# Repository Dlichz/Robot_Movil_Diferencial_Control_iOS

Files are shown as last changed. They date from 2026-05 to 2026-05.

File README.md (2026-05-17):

# 🤖 Robot Móvil Diferencial con Control iOS

> Diseño, construcción y programación de un robot móvil de tracción diferencial controlado de forma inalámbrica desde una app iOS nativa, con evasión autónoma de obstáculos y telemetría en tiempo real.

---

## 🎯 Objetivo General

Diseñar, construir y programar un robot móvil de tracción diferencial controlado de forma inalámbrica desde una aplicación iOS nativa, integrando evasión autónoma de obstáculos, navegación precisa y telemetría en tiempo real.

---

## 📌 Objetivos Específicos

| # | Objetivo | Criterio de Éxito |
|---|---|---|
| 1 | **Hardware y energía** — Implementar un sistema electrónico basado en ESP32 con drivers TB6612FNG, motores N20 con encoder y alimentación LiPo 2S regulada y protegida | Sistema energizado y estable sin sobrecalentamiento |
| 2 | **Control de movimiento** — Lograr giros precisos usando encoders y MPU-6050 con controlador PID | Error promedio < 5° en 10 giros consecutivos de 90° y 180° |
| 3 | **Evasión autónoma** — Detectar obstáculos con VL53L0X y ejecutar maniobra de evasión con prioridad sobre el comando manual | 0 colisiones en 10 pruebas consecutivas con obstáculos a ≤ 20 cm |
| 4 | **Control remoto iOS** — Desarrollar app nativa en Swift con comunicación Bluetooth BLE para comandos en tiempo real | Latencia de respuesta < 100 ms desde la app |
| 5 | **Telemetría en tiempo real** — Visualizar en la app: distancia al obstáculo, velocidad estimada, orientación (yaw) y nivel de batería | Datos actualizados cada ≤ 200 ms |
| 6 | **Chasis 3D** — Diseñar e imprimir un chasis que integre todos los componentes de forma ordenada y desmontable | Todos los componentes fijos, accesibles y sin cables sueltos |

---

## 🛠️ Hardware

### Componentes principales

| Componente | Función |
|---|---|
| ESP32 (Dev Board) | Cerebro del sistema — Bluetooth BLE, lógica de control |
| 2× Motor N20 con encoder | Tracción diferencial con odometría |
| TB6612FNG | Driver de motores de alta eficiencia |
| VL53L0X (ToF) | Detección de obstáculos por láser (±1 mm) |
| MPU-6050 | IMU — acelerómetro + giroscopio para navegación precisa |
| LiPo 2S 7.4V 2200mAh | Fuente de energía principal |
| Módulo Mini-360 | Regulador buck 7.4V → 5V |
| Módulo JESSINIE Tipo C | Carga integrada vía USB-C |
| Ruedas 43mm + ball casters | Sistema de rodadura (tracción diferencial) |
| Chasis impreso en 3D | Estructura diseñada a medida |

### Sistema de energía

```
Batería LiPo 2S (7.4V)
    │
    ├─── Interruptor ON/OFF
    │
    ├─── Fusible PPTC (protección contra cortocircuito)
    │
    ├─── Mini-360 Buck → 5V ──→ ESP32 + Sensores
    │
    └─── TB6612FNG ──────────→ Motores N20
```

---

## 📱 Funcionalidades

- **Control manual** desde app iOS nativa (Swift + CoreBluetooth)
- **Evasión autónoma** de obstáculos en tiempo real (prioridad sobre comando manual)
- **Giros precisos** de 90° y 180° mediante fusión sensorial encoder + IMU
- **Telemetría en vivo** en la app: distancia, velocidad, orientación, batería

---

## 🗂️ Estructura del Repositorio

```
/
├── firmware/          # Código fuente ESP32 (C++ / Arduino framework)
│   ├── src/
│   └── platformio.ini
├── ios-app/           # Aplicación iOS nativa en Swift
├── hardware/          # Esquemáticos y lista de materiales (BOM)
├── cad/               # Archivos del chasis 3D (.f3d / .stl)
├── docs/              # Documento técnico del proyecto por etapas
└── media/             # Fotos y videos de cada etapa
```

---

## 🚀 Etapas del Proyecto

- [x] Definición de objetivos y arquitectura del sistema
- [ ] **Etapa 1** — Control básico de motores (TB6612FNG + N20 + encoders)
- [ ] **Etapa 2** — Comunicación Bluetooth BLE (ESP32 ↔ iPhone)
- [ ] **Etapa 3** — Sensor ToF + lógica de evasión
- [ ] **Etapa 4** — IMU + fusión sensorial + giros precisos (PID)
- [ ] **Etapa 5** — Diseño e impresión del chasis 3D + integración final
- [ ] **Etapa 6** — Pruebas, métricas y documentación final

---

## 🧰 Stack Tecnológico

| Capa | Tecnología |
|---|---|
| Firmware | C++ / Arduino Framework (PlatformIO) |
| Comunicación | Bluetooth BLE (ESP32 ↔ CoreBluetooth) |
| App móvil | Swift (iOS nativo) |
| CAD | Fusion 360 |
| Documentación | Markdown + PDF |

---

## 👤 Autor

**Francisco David Zárate Vásquez: Ingeniero Mecatrónico** — Proyecto de desarrollo técnico personal que combina electrónica, mecánica, control de sistemas y desarrollo de software iOS.

---

## 📄 Licencia

MIT License — libre para usar, modificar y distribuir con atribución.

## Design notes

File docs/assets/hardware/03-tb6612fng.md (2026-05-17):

# Driver de Motores: TB6612FNG

> **Componente:** Driver dual de motores DC con puente H
> **Fabricante:** Toshiba (chip), SparkFun/genéricos (módulo breakout)
> **Función en el robot:** Controlar dirección y velocidad de los dos motores N20

---

## 📑 Tabla de contenidos

- [¿Por qué este componente?](#por-qué-este-componente)
- [¿Qué es y cómo funciona?](#qué-es-y-cómo-funciona)
- [Especificaciones técnicas](#especificaciones-técnicas)
- [Pinout y conexiones](#pinout-y-conexiones)
- [Lógica de control](#lógica-de-control)
- [Sistema de doble alimentación](#sistema-de-doble-alimentación)
- [Comparación con alternativas](#comparación-con-alternativas)
- [Imágenes y referencias](#imágenes-y-referencias)

---

## ¿Por qué este componente?

El ESP32 es un microcontrolador de bajo voltaje (3.3V) y baja corriente (~40 mA por pin). No puede alimentar directamente motores DC, que requieren:

- Voltaje mayor (típicamente 6V–12V)
- Corrientes de 200–500 mA en operación normal, con picos al arrancar
- Capacidad de invertir polaridad para cambiar dirección de giro

Si se conectaran los motores directamente al ESP32:

- Se quemaría el microcontrolador al instante
- Los motores apenas se moverían (poca corriente, bajo voltaje)
- No se podría controlar la dirección de giro

El **TB6612FNG** resuelve esto actuando como intermediario entre el ESP32 y los motores. Recibe señales lógicas de baja potencia y entrega alta corriente a los motores desde una fuente separada (la batería LiPo).

### Razones específicas de elección

1. **Alta eficiencia (~90%)** gracias al uso de MOSFETs en lugar de transistores BJT
2. **Baja caída de voltaje (0.5V)** — los motores reciben casi todo el voltaje de la batería
3. **Bajo calor generado** — no necesita disipador para corrientes pequeñas (motores N20)
4. **Tamaño compacto** — ideal para robots pequeños
5. **Dual integrado** — un solo chip controla los dos motores del robot diferencial

---

## ¿Qué es y cómo funciona?

El TB6612FNG es un driver de motores DC con **dos puentes H** integrados, uno por cada motor.

### El concepto del puente H

Un puente H es un circuito con cuatro interruptores (en este caso, MOSFETs) dispuestos alrededor del motor:

```
         VCC (motor)
              │
         ┌────┴────┐
         │         │
         S1       S3
         │         │
         ├─[Motor]─┤
         │         │
         S2       S4
         │         │
         └────┬────┘
              │
             GND
```

Al cerrar diferentes combinaciones de interruptores, se controla el flujo de corriente a través del motor:

| Acción | Interruptores cerrados | Efecto |
|---|---|---|
| Adelante | S1 + S4 | Corriente fluye izquierda → derecha |
| Atrás | S2 + S3 | Corriente fluye derecha → izquierda |
| Freno activo | S1 + S3 (o S2 + S4) | Cortocircuito controlado del motor |
| Coast (libre) | Ninguno | Motor gira por inercia |

El TB6612FNG implementa esta lógica internamente con MOSFETs, controlados desde fuera mediante señales lógicas simples (HIGH/LOW).

### Control de velocidad con PWM

Además de la dirección, el TB6612FNG permite controlar la velocidad mediante **PWM** (Pulse Width Modulation). En lugar de aplicar 7.4V constantes, aplica pulsos rápidos cuyo "ancho" determina la potencia promedio:

- PWM al 100% → motor a velocidad máxima
- PWM al 50% → motor a media velocidad
- PWM al 0% → motor detenido

El ESP32 genera la señal PWM por hardware usando su periférico **LEDC**, sin gastar ciclos de CPU.

---

## Especificaciones técnicas

| Parámetro | Valor |
|---|---|
| Voltaje de motores (VM) | 2.5V – 13.5V |
| Voltaje de lógica (VCC) | 2.7V – 5.5V |
| Corriente continua por canal | 1.2 A |
| Corriente pico por canal | 3.2 A |
| Frecuencia PWM máxima | 100 kHz |
| Canales de motor | 2 (Motor A y Motor B) |
| Tecnología interna | MOSFET (mayor eficiencia que BJT) |
| Protecciones incluidas | Térmica, bajo voltaje, sobre-corriente |

---

## Pinout y conexiones

El módulo TB6612FNG tiene tres grupos de pines:

### Grupo 1: Alimentación

| Pin | Función | Conexión en el robot |
|---|---|---|
| **VM** | Voltaje para motores | Batería LiPo 2S (+7.4V) directo |
| **VCC** | Voltaje para lógica del chip | 5V regulado desde Mini-360 |
| **GND** | Tierra | GND común con ESP32 y batería |

> ⚠️ VM y VCC son independientes. Esto permite alimentar motores con alto voltaje mientras la lógica del chip opera con voltaje bajo y estable.

### Grupo 2: Señales de control desde el ESP32

| Pin TB6612FNG | Pin ESP32 | Función |
|---|---|---|
| STBY | GPIO 13 | Standby — HIGH activa el chip, LOW lo apaga |
| PWMA | GPIO 25 | PWM Motor A — controla velocidad (0–255) |
| AIN1 | GPIO 26 | Dirección Motor A (bit 1) |
| AIN2 | GPIO 27 | Dirección Motor A (bit 2) |
| PWMB | GPIO 33 | PWM Motor B — controla velocidad (0–255) |
| BIN1 | GPIO 14 | Dirección Motor B (bit 1) |
| BIN2 | GPIO 12 | Dirección Motor B (bit 2) |

### Grupo 3: Salidas a motores

| Pin TB6612FNG | Conexión |
|---|---|
| AO1 | Motor A — cable (+) |
| AO2 | Motor A — cable (−) |
| BO1 | Motor B — cable (+) |
| BO2 | Motor B — cable (−) |

> 💡 La polaridad del motor (qué cable va a AO1 y cuál a AO2) determina qué dirección se considera "adelante". Si el motor gira al revés, basta con invertir AO1↔AO2 o cambiar la lógica en el código.

---

## Lógica de control

Para cada motor, la combinación de IN1, IN2 y PWM determina su comportamiento:

| IN1 | IN2 | PWM | Estado del motor |
|---|---|---|---|
| HIGH | LOW | 0–255 | Adelante (velocidad según PWM) |
| LOW | HIGH | 0–255 | Atrás (velocidad según PWM) |
| HIGH | HIGH | cualquiera | Freno activo (short brake) |
| LOW | LOW | cualquiera | Coast (motor libre, gira por inercia) |
| cualquiera | cualquiera | 0 | Detenido |

### Ejemplo de código

```cpp
// Motor A hacia adelante a velocidad media
digitalWrite(AIN1, HIGH);
digitalWrite(AIN2, LOW);
ledcWrite(canalPWMA, 128);   // 128/255 ≈ 50%

// Motor A hacia atrás a velocidad máxima
digitalWrite(AIN1, LOW);
digitalWrite(AIN2, HIGH);
ledcWrite(canalPWMA, 255);

// Frenar Motor A
digitalWrite(AIN1, HIGH);
digitalWrite(AIN2, HIGH);
```

### Sobre el pin STBY

El pin **STBY (Standby)** actúa como interruptor maestro del chip:

- **STBY = HIGH** → Chip activo, los motores responden a las señales
- **STBY = LOW** → Chip en bajo consumo, los motores no se mueven sin importar las señales

En el firmware, STBY se pone en HIGH una vez al iniciar (`setup()`). Olvidarlo es un error común que causa que el robot no se mueva aunque el código parezca correcto.

---

## Sistema de doble alimentación

```
                    Batería LiPo 2S (7.4V)
                           │
                           ├──→ VM (motores reciben 7.4V)
                           │
                    Mini-360 (regulador DC-DC)
                           │
                           ├──→ 5V → ESP32 VIN
                           │
                           ├──→ 5V → TB6612FNG VCC (lógica)
                           │
                           └──→ GND común a todo el sistema
```

### ¿Por qué dos fuentes separadas?

1. Los **motores** consumen corrientes grandes y generan picos al arrancar
2. La **lógica** del ESP32 y del chip TB6612FNG necesita voltaje estable
3. Si todo compartiera el mismo riel, los picos de corriente del motor causarían caídas de voltaje que podrían reiniciar el ESP32 o introducir errores

Esta separación es **estándar en cualquier robot móvil bien diseñado** y aumenta significativamente la fiabilidad del sistema.

---

## Comparación con alternativas

| Característica | TB6612FNG | L298N | DRV8833 |
|---|---|---|---|
| Tecnología interna | MOSFET | BJT (Darlington) | MOSFET |
| Eficiencia | ~90% | ~60% | ~90% |
| Caída de voltaje | 0.5V | 2.0V+ | 0.5V |
| Corriente continua | 1.2 A | 2.0 A | 1.5 A |
| Calor generado | Bajo | Alto (necesita disipador) | Bajo |
| Tamaño del módulo | Pequeño | Grande | Muy pequeño |
| Costo aproximado | $3 USD | $2 USD | $3 USD |
| Recomendado para | Robots pequeños/medianos | Motores grandes | Robots muy compactos |

### ¿Por qué TB6612FNG y no L298N?

El L298N es más común en kits para principiantes, pero tiene desventajas serias para este proyecto:

- Pierde 2V o más como calor → la batería se descarga más rápido
- Requiere disipador térmico → más volumen
- Menor eficiencia → menor autonomía del robot

El TB6612FNG aprovecha mejor cada miliamperio de la batería LiPo, lo cual es crítico en un robot pequeño con batería limitada.

---

## Imágenes y referencias

### Fotos del componente

<!-- TODO: Agregar fotos -->
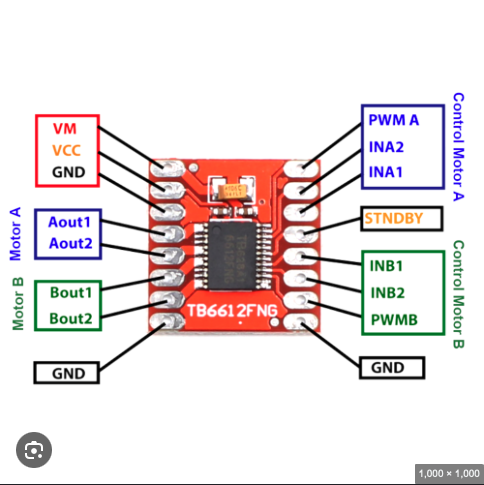
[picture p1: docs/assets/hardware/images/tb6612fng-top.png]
Módulo TB6612FNG vista superior

### Diagrama de conexiones en el robot

<!-- TODO: Exportar diagrama de Fritzing aquí -->
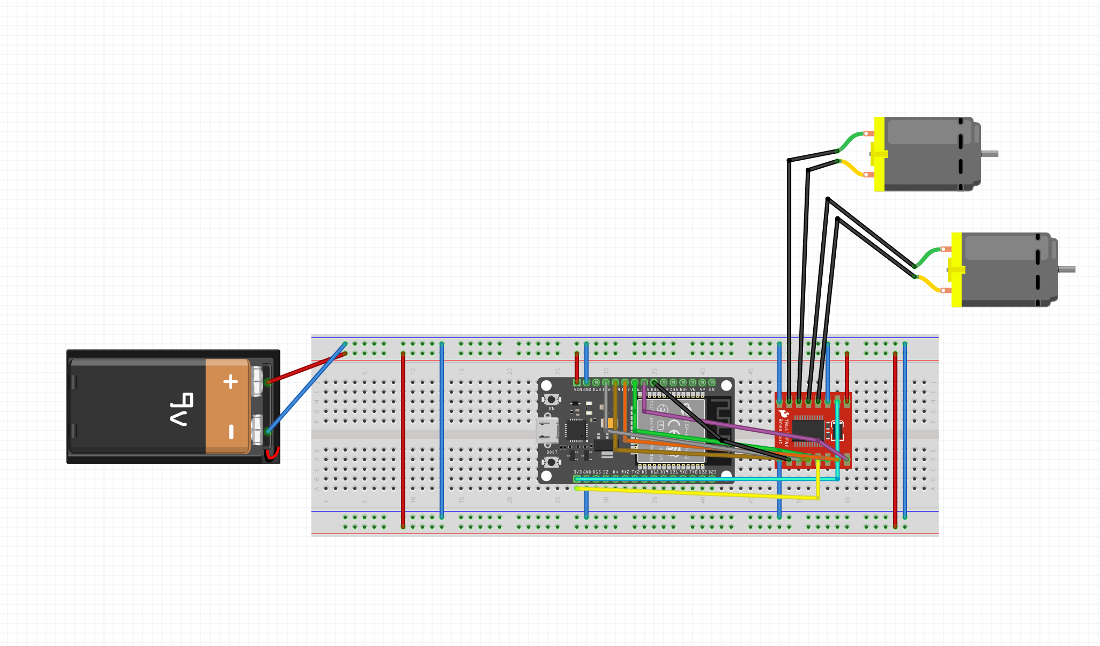
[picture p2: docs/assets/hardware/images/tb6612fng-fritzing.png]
Conexión TB6612FNG + ESP32 + motores

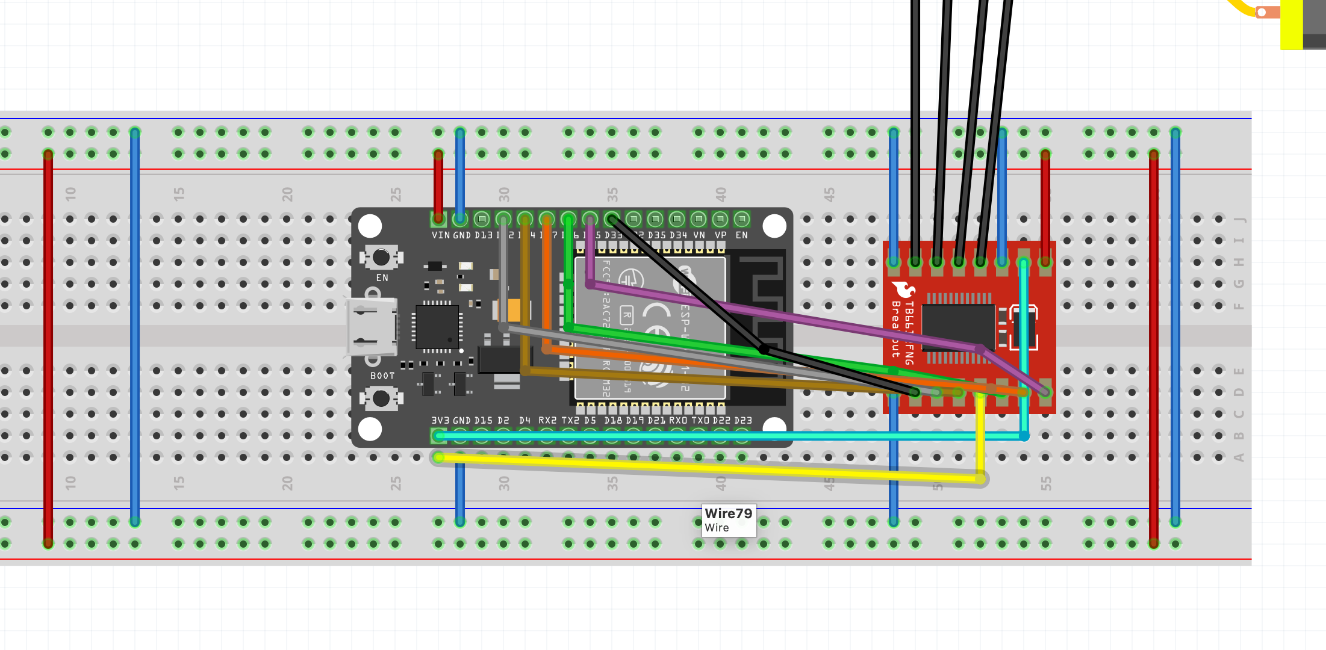
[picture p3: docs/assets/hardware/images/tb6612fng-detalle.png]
Detalle de conexión


### Documentos de referencia

- [Datasheet oficial Toshiba TB6612FNG](https://www.sparkfun.com/datasheets/Robotics/TB6612FNG.pdf)
- [Hookup Guide de SparkFun](https://learn.sparkfun.com/tutorials/tb6612fng-hookup-guide)
- [Librería oficial SparkFun TB6612FNG (Arduino)](https://github.com/sparkfun/SparkFun_TB6612FNG_Arduino_Library)

---

## Notas de implementación

### Estado actual en el proyecto

- [x] Componente seleccionado y justificado
- [x] Pinout definido para integración con ESP32
- [x] Código base de control implementado (`src/main.cpp`)
- [x] Lógica validada en simulación (Wokwi)
- [x] Diagrama de cableado en Fritzing
- [ ] Pruebas con hardware real
- [ ] Ajuste fino de PWM según comportamiento de los motores N20

### Próximos pasos

1. Simular conexión en proteus o similar
2. Conectar físicamente sobre protoboard y validar lógica
3. Integrar con encoders para control de velocidad en lazo cerrado
4. Caracterizar respuesta motor → PWM real

---

*Documento mantenido por: Francisco David Zárate Vásquez*
*Última actualización: 16 de mayo 2026*

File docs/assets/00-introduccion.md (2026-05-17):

# 00. Introducción

## 1. Descripción del Proyecto

Este proyecto consiste en el diseño, construcción y programación de un robot móvil de tracción diferencial controlado de forma inalámbrica desde una aplicación iOS nativa. El sistema integra evasión autónoma de obstáculos, navegación precisa mediante fusión sensorial y telemetría en tiempo real visualizada desde un iPhone.

El proyecto combina disciplinas de electrónica, mecánica, control de sistemas y desarrollo de software móvil, representando una aplicación práctica completa de la ingeniería mecatrónica.

---

## 2. Motivación

La ingeniería mecatrónica integra mecánica, electrónica, control y programación. Sin embargo, pocas veces se tienen la oportunidad de aplicar todas estas áreas en un solo proyecto personal, fuera del entorno académico o laboral formal.

Este proyecto nace de la intención de poner a prueba esos conocimientos de forma autónoma, añadiendo además el desarrollo de una aplicación iOS nativa como diferenciador técnico. La combinación de un sistema embebido en ESP32 con una app desarrollada en Swift representa un stack tecnológico completo de extremo a extremo, desde el firmware hasta la interfaz de usuario.

---

## 3. Objetivo General

Diseñar, construir y programar un robot móvil de tracción diferencial controlado de forma inalámbrica desde una aplicación iOS nativa, integrando evasión autónoma de obstáculos, navegación precisa y telemetría en tiempo real.

---

## 4. Objetivos Específicos

### 4.1 Hardware y Sistema de Energía
Implementar un sistema electrónico funcional basado en ESP32, con driver TB6612FNG, motores N20 con encoder y alimentación LiPo 2S regulada y protegida mediante fusible PPTC y módulo buck Mini-360.

**Criterio de éxito:** Sistema energizado y estable sin sobrecalentamiento durante operación continua.

### 4.2 Control de Movimiento Preciso
Lograr giros de 90° y 180° con error promedio menor a 5°, mediante un controlador PID que fusiona la información de los encoders de los motores N20 y el giroscopio del MPU-6050.

**Criterio de éxito:** Error promedio < 5° en 10 giros consecutivos de cada ángulo.

### 4.3 Evasión Autónoma de Obstáculos
Implementar un comportamiento reactivo que detecte obstáculos mediante el sensor ToF VL53L0X a una distancia menor o igual a 20 cm, ejecutando una maniobra de evasión en menos de 500 ms con prioridad sobre cualquier comando manual.

**Criterio de éxito:** Cero colisiones en 10 pruebas consecutivas con obstáculos a ≤ 20 cm.

### 4.4 Control Remoto desde iPhone
Desarrollar una aplicación iOS nativa en Swift que se comunique con el ESP32 mediante Bluetooth BLE (CoreBluetooth) para enviar comandos de movimiento en tiempo real.

**Criterio de éxito:** Latencia de respuesta menor a 100 ms desde la interacción en la app hasta la respuesta del robot.

### 4.5 Telemetría en Tiempo Real
Visualizar en la app iOS datos del robot actualizados en vivo: distancia al obstáculo más cercano, velocidad estimada, orientación (yaw) y nivel de batería.

**Criterio de éxito:** Datos actualizados cada ≤ 200 ms sin pérdida de conexión en operación normal.

### 4.6 Chasis Diseñado a Medida
Diseñar e imprimir en 3D un chasis que integre todos los componentes de forma ordenada, accesible para mantenimiento y sin cables sueltos.

**Criterio de éxito:** Todos los componentes fijos y desmontables sin necesidad de herramientas especiales.

---

## 5. Alcances

- El robot opera en superficies planas de interiores (escritorio, mesa).
- El control remoto funciona dentro del rango Bluetooth BLE (aproximadamente 10 metros en interiores).
- La evasión de obstáculos es reactiva, no predictiva — el robot responde al obstáculo cuando lo detecta, no planifica rutas.
- La app iOS es compatible con iPhone (iOS 16 en adelante).
- El sistema de carga es integrado mediante puerto USB-C.

---

## 6. Limitaciones

- No se implementa navegación autónoma completa ni mapeo del entorno (SLAM).
- El robot no está diseñado para superficies irregulares, rampas o exteriores.
- La app no incluye modo multijugador ni control desde múltiples dispositivos simultáneamente.
- La precisión de la odometría puede degradarse en superficies con poca fricción.

---

## 7. Estructura del Documento

| Capítulo | Contenido |
|---|---|
| 00. Introducción | Este documento — contexto, objetivos, alcances |
| 01. Marco Teórico | Fundamentos técnicos de cada subsistema |
| 02. Diseño de Hardware | Componentes, esquemáticos, sistema de energía, chasis |
| 03. Diseño de Firmware | Arquitectura de software del ESP32, PID, BLE |
| 04. Aplicación iOS | Arquitectura de la app, CoreBluetooth, telemetría |
| 05. Pruebas y Resultados | Métricas reales, tablas, gráficas comparativas |
| 06. Conclusiones | Logros, problemas resueltos, trabajo futuro |

---

*Última actualización: Mayo 2026*

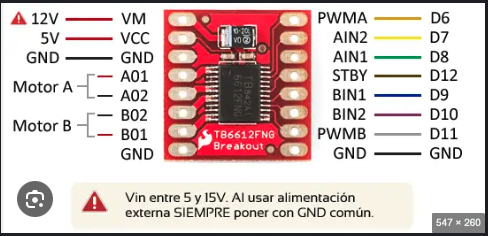
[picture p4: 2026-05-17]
docs/assets/hardware/images/tb6612fng-pinout.png

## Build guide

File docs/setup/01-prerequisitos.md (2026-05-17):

# 01 — Prerrequisitos

> Antes de instalar las herramientas, necesitas tener listo el sistema, las cuentas y el hardware básico.

---

## 💻 Sistema operativo

### macOS (recomendado, este proyecto se desarrolló aquí)

- **Versión mínima:** macOS 12 (Monterey) o superior
- **Versión usada en el proyecto:** macOS Sonoma / Sequoia
- **Chip:** Intel o Apple Silicon (M1/M2/M3/M4) — ambos funcionan

### Linux

- Ubuntu 20.04+, Fedora 36+, o equivalente
- Todas las herramientas funcionan, pero algunos comandos de las guías cambian

### Windows

- Windows 10 o 11
- Algunas herramientas (como Fritzing) tienen mejor experiencia en Mac/Linux

---

## 🛠️ Hardware necesario

### Mínimo para empezar

- Computadora con al menos 8 GB de RAM
- 10 GB de espacio libre en disco
- Conexión a internet estable

### Para programar el robot

- **ESP32 DevKit V1** (30 pines, basado en ESP32-WROOM-32)
- **Cable USB con datos** (NO solo de carga)
  - Recomendado: USB-A a Micro-USB, o USB-C a Micro-USB

### Para el robot completo (no necesario para programar)

- Driver de motores TB6612FNG
- 2× Micro motorreductor N20 con encoder
- Sensor ToF VL53L0X
- Giroscopio MPU-6050
- Batería LiPo 2S 7.4V 2200 mAh
- Módulo de carga USB-C para LiPo 2S
- 2× Módulos Mini-360 (reguladores DC-DC)
- Interruptor SPST + fusible PPTC
- Protoboard + cables jumper
- Multímetro (opcional, muy recomendado)

---

## 👤 Cuentas necesarias

### Obligatorias

| Servicio | Para qué |
|---|---|
| [GitHub](https://github.com) | Versionado del código, descargar el repositorio |
| [Wokwi](https://wokwi.com) | Simulador online (login con GitHub o Google) |

### Opcionales (recomendadas)

| Servicio | Para qué |
|---|---|
| [Fritzing](https://fritzing.org) | Si quieres compartir tus diagramas |
| [Foro de Fritzing](https://forum.fritzing.org) | Descargar componentes custom |
| [PlatformIO](https://platformio.org) | No estrictamente necesaria pero útil |

---

## 🔧 Conocimientos previos útiles (no obligatorios)

Este proyecto está documentado para que cualquiera pueda seguirlo, pero te será más fácil si tienes nociones básicas de:

- **Programación en C/C++** o cualquier lenguaje
- **Electrónica básica** (qué es voltaje, corriente, resistencia)
- **Línea de comandos** (terminal de Mac/Linux)
- **Git** (clonar repositorios, commits)

Si no tienes ninguno de estos, no te preocupes — las guías incluyen explicaciones de los conceptos clave.

---

## ✅ Checklist antes de continuar

Antes de pasar a la siguiente guía, asegúrate de tener:

- [ ] Tu Mac/PC con el sistema operativo actualizado
- [ ] Al menos 10 GB de espacio libre en disco
- [ ] Cuenta de GitHub creada
- [ ] Conexión a internet estable
- [ ] (Opcional) ESP32 + cable USB para pruebas con hardware real

---

## 🆘 Problemas comunes

### "Mi Mac es antiguo, ¿funcionará?"

Si tu Mac soporta macOS 12 o superior, sí. Cualquier MacBook desde 2017 en adelante debería andar sin problemas.

### "Tengo Windows, ¿puedo seguir el proyecto?"

Sí, pero las guías están escritas con comandos de Mac. Necesitarás traducir algunos a PowerShell o cmd. La lógica es idéntica.

### "No tengo el ESP32 todavía"

No hay problema. Puedes:
1. Hacer todo el setup
2. Escribir y compilar el código
3. Simular en Wokwi (no requiere hardware)

El hardware solo es necesario para la fase final de pruebas.

---

[← Volver al índice](README.md) | [Siguiente: VS Code →](02-vscode.md)

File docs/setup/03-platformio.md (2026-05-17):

# 03 — PlatformIO

> **PlatformIO** es el sistema de build profesional para microcontroladores. Es lo que toma tu código C++ y lo convierte en un binario que el ESP32 puede ejecutar.

---

## 🎯 ¿Qué es PlatformIO?

PlatformIO es un ecosistema de desarrollo de software libre y de código abierto para sistemas embebidos y aplicaciones de Internet de las Cosas. Maneja:

- **Compilación** del código C++ a binario para ESP32 (u otros chips)
- **Descarga de librerías** automáticamente
- **Gestión de toolchains** (compiladores específicos)
- **Subida del firmware** a la placa
- **Monitoreo del puerto serial**
- **Tests unitarios**

---

## 🆚 ¿Por qué no Arduino IDE?

| Característica | Arduino IDE | PlatformIO |
|---|---|---|
| Compilación | Sí | Sí (más rápido) |
| Gestión de librerías | Manual | Automática (declaras en `platformio.ini`) |
| Estructura del proyecto | Plana, 1 archivo `.ino` | Profesional, separa `src/`, `lib/`, `include/`, `test/` |
| IDE | Propio (limitado) | Funciona en VS Code (mucho mejor) |
| Soporta múltiples chips | Sí, con plugins | Sí, nativo (1000+ placas) |
| Reproducibilidad | Dependiente del entorno | Configuración versionable en `platformio.ini` |
| Industria | Hobby | Profesional |

PlatformIO es **profesional**.

---

## 📥 Instalación

PlatformIO se instala como **extensión de VS Code**, no como aplicación independiente.

### Pasos

1. Abre VS Code
2. Ve al panel de extensiones (`Cmd + Shift + X`)
3. Busca **"PlatformIO IDE"**
4. Click en **"Install"**
5. ⏳ Espera 3-5 minutos
   - PlatformIO descarga:
     - Python embebido (~100 MB)
     - Toolchain de Xtensa para ESP32 (~150 MB)
     - Framework de Arduino para ESP32 (~50 MB)
6. Cuando termine, VS Code pedirá reiniciar — acepta
7. Al reabrir, verás la **carita de alien** 👽 en la barra lateral izquierda

### Verificación

Click en el ícono 👽 → debería aparecer un panel con "PROJECT TASKS", "QUICK ACCESS", "Debug", "Miscellaneous".

---

## 🎓 Conceptos clave

### El archivo `platformio.ini`

Es el **corazón** del proyecto. Define qué chip, qué framework y qué librerías usar.

Ejemplo del archivo de este proyecto:

```ini
[env:esp32dev]
platform = espressif32
board = esp32dev
framework = arduino
monitor_speed = 115200
```

Línea por línea:

| Línea | Significado |
|---|---|
| `[env:esp32dev]` | Nombre del entorno. Puedes tener varios (por ej. `[env:esp32]`, `[env:esp32-debug]`) |
| `platform = espressif32` | Familia de chips (Espressif = ESP32, ESP8266) |
| `board = esp32dev` | Modelo específico de placa (ESP32 DevKit V1) |
| `framework = arduino` | Framework de programación (alternativa: ESP-IDF) |
| `monitor_speed = 115200` | Velocidad del puerto serial en baudios |

### Estructura de un proyecto PlatformIO

```
mi-proyecto/
├── platformio.ini          # Configuración del proyecto
├── src/
│   └── main.cpp            # Código principal
├── include/                # Headers personalizados (.h)
├── lib/                    # Librerías propias del proyecto
├── test/                   # Tests unitarios
└── .pio/                   # Carpeta generada (NO editar, NO subir a Git)
    └── build/
        └── esp32dev/
            ├── firmware.bin    # Binario compilado
            └── firmware.elf    # Versión con info de debug
```

### Diferencias con Arduino IDE

| Arduino IDE | PlatformIO |
|---|---|
| Un solo archivo `.ino` | Múltiples `.cpp` y `.h` en `src/` |
| `#include <Arduino.h>` automático | Debes incluirlo manualmente |
| Funciones se pueden usar antes de declararlas | Necesitas declaraciones adelantadas |
| Librerías globales | Librerías por proyecto |

---

## 🛠️ Comandos esenciales

PlatformIO funciona tanto por **interfaz gráfica** (botones en VS Code) como por **terminal** (`pio`).

### Por terminal

| Comando | Descripción |
|---|---|
| `pio run` | Compilar |
| `pio run --target upload` | Compilar + subir al ESP32 |
| `pio run --target clean` | Limpiar archivos compilados |
| `pio device monitor` | Abrir monitor serial |
| `pio device list` | Listar puertos seriales detectados |
| `pio update` | Actualizar plataformas y librerías |
| `pio platform list` | Ver plataformas instaladas |

### Por interfaz gráfica

En la barra inferior azul de VS Code aparecen estos íconos (de izquierda a derecha):

| Ícono | Función | Equivalente terminal |
|---|---|---|
| 🏠 | PIO Home | — |
| ✓ | Build | `pio run` |
| → | Upload | `pio run --target upload` |
| 🗑️ | Clean | `pio run --target clean` |
| 📁 | Tasks | — |
| ⚡ | Serial Monitor | `pio device monitor` |

---

## 🚀 Crear un proyecto nuevo (referencia)

Si quieres empezar otro proyecto en el futuro:

1. Click en el ícono 👽 de PlatformIO
2. Click en **"PIO Home"** → **"+ New Project"**
3. Llena:
   - **Name:** nombre del proyecto
   - **Board:** busca tu placa (ej. `ESP32 Dev Module`)
   - **Framework:** `Arduino`
   - **Location:** carpeta donde guardarlo
4. Click **"Finish"**
5. Espera a que se inicialice

Para este proyecto, **no necesitas crear uno nuevo** — ya está creado en `firmware/esp32/`.

---

## 🔧 Cómo agregar una librería

Cuando llegues a sensores, vas a necesitar librerías como Adafruit_MPU6050 o Adafruit_VL53L0X.

### Método 1: Editar `platformio.ini` (recomendado, versionable)

Agrega bajo el entorno:

```ini
[env:esp32dev]
platform = espressif32
board = esp32dev
framework = arduino
monitor_speed = 115200
lib_deps =
    adafruit/Adafruit MPU6050 @ ^2.2.4
    adafruit/Adafruit VL53L0X @ ^1.2.4
```

La próxima vez que compiles, PlatformIO las descarga automáticamente.

### Método 2: Por interfaz

1. Click en el ícono 👽
2. **PIO Home → Libraries**
3. Busca la librería
4. Click en **"Add to Project"**

---

## 🆘 Problemas comunes

### "command not found: pio"

Pasa cuando usas una terminal externa (no la integrada de VS Code).

**Solución 1:** Usa la terminal interna de VS Code (`Ctrl + ñ`). Esa SÍ tiene `pio` en el PATH.

**Solución 2 (permanente):** Agrega esta línea a tu `~/.zshrc`:

```bash
export PATH="$PATH:$HOME/.platformio/penv/bin"
```

Luego ejecuta `source ~/.zshrc` para aplicar el cambio.

### "Failed to connect to ESP32: Wrong boot mode detected"

El ESP32 está en estado raro.

**Solución:** Mantén presionado el botón **BOOT** (o **IO0**) en la placa mientras inicias el upload. Suéltalo cuando empiece a escribir.

### "Permission denied: /dev/cu.usbserial-XXXX"

En Mac, a veces el puerto serial no tiene permisos.

**Solución:**
```bash
sudo chmod 666 /dev/cu.usbserial-0001
```

### "Compilación tarda muchísimo la primera vez"

**Es normal.** La primera vez PlatformIO descarga el toolchain (~200 MB). Las siguientes compilaciones son rápidas (5-15 segundos).

### "Errores que `Serial` no existe, `pinMode` no existe..."

Falta `#include <Arduino.h>` al inicio de `main.cpp`. En PlatformIO no es automático como en Arduino IDE.

---

## ✅ Checklist al terminar

- [ ] PlatformIO instalado como extensión
- [ ] Veo el ícono 👽 en VS Code
- [ ] Puedo abrir el proyecto `firmware/esp32/` y ver `platformio.ini`
- [ ] Sé compilar con el botón ✓ o con `pio run`
- [ ] Sé que el binario sale en `.pio/build/esp32dev/firmware.bin`

---

[← Anterior: VS Code](02-vscode.md) | [Siguiente: Wokwi →](04-wokwi.md)

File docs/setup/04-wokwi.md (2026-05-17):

# 04 — Wokwi

> **Wokwi** es un simulador online de microcontroladores. Permite probar tu código sin tener el hardware físico, ideal para validar lógica antes de invertir en componentes.

---

## 🎯 ¿Qué hace Wokwi?

- Simula el ESP32 (y muchos otros chips) ejecutando tu código real
- Provee componentes virtuales (LEDs, sensores, pantallas)
- Tiene **analizador lógico** y monitor serial integrados
- Soporta WiFi y Bluetooth simulados (limitado)

---

## 🆚 Dos formas de usar Wokwi

### Opción A: Wokwi en el navegador (recomendada para empezar)

- **URL:** https://wokwi.com
- **Ventajas:** Sin instalaciones, compila en sus servidores, siempre funciona
- **Desventajas:** Requiere internet, no integra con tu proyecto PlatformIO

### Opción B: Extensión Wokwi para VS Code

- Se instala como extensión
- Usa el `firmware.bin` compilado por PlatformIO
- **Ventajas:** Integrado con tu flujo de desarrollo
- **Desventajas:** Tiene bugs ocasionales en Mac (especialmente el monitor serial)

⚠️ **Recomendación del proyecto:** Para esta etapa, usa **Wokwi en el navegador**. Es más estable y rápido.

---

## 🌐 Opción A: Wokwi en el navegador

### Setup inicial

1. Ve a **https://wokwi.com**
2. Click en **"Log in"** (arriba a la derecha)
3. Inicia sesión con GitHub o Google
4. Listo, no requiere instalación

### Cómo abrir el proyecto

#### Método 1: Crear desde cero

1. Click en **"New Project"** → **"ESP32"**
2. Se abre un editor con 2 archivos:
   - `sketch.ino` — código (formato Arduino)
   - `diagram.json` — esquemático

#### Método 2: Cargar el proyecto existente

1. Abre **https://wokwi.com**
2. Click en **"New Project"** → **"ESP32"**
3. En la pestaña **`sketch.ino`**, borra el contenido y pega el código de `firmware/esp32/src/main.cpp`
   - ⚠️ **Importante:** quita la línea `#include <Arduino.h>` (Wokwi web no la necesita)
4. En la pestaña **`diagram.json`**, borra y pega el contenido de `firmware/esp32/diagram.json`
5. Click en el botón **▶ verde** para arrancar la simulación

### Interfaz de Wokwi web

```
┌──────────────────────────────────────────────────────┐
│  💾 SAVE  📤 SHARE   nombre-proyecto                  │
├──────────────────────────────────────────────────────┤
│                                                       │
│  [sketch.ino] [diagram.json] [Library Manager]        │
│                                                       │
│  Aquí escribes/pegas el código                        │
│                                                       │
│                                                       │
├────────────────────────┬─────────────────────────────┤
│                        │ [Simulation]                 │
│                        │  ▶ ⏸ 🔄  (controles)        │
│                        │                              │
│                        │  Aquí aparece el circuito    │
│                        │                              │
│  Monitor Serial:       │                              │
│  > _                   │                              │
└────────────────────────┴─────────────────────────────┘
```

### Cómo usar el monitor serial

1. Después de darle ▶ Play, busca el **monitor serial** en la parte inferior izquierda
2. Si no aparece, presiona **`Ctrl + Shift + S`** para mostrarlo
3. Click dentro del monitor → escribe comandos (ej. `w`)
4. Presiona Enter

---

## 💻 Opción B: Wokwi como extensión de VS Code

### Instalación

1. En VS Code, ve al panel de extensiones (`Cmd + Shift + X`)
2. Busca **"Wokwi Simulator"**
3. Click en **"Install"**
4. Reinicia VS Code

### Activar licencia gratuita

Wokwi requiere licencia incluso en su versión gratis (para uso personal).

1. `Cmd + Shift + P` → escribe **"Wokwi: Request a new License"**
2. Se abre el navegador
3. Inicia sesión con GitHub o Google
4. Acepta los términos
5. Vuelve a VS Code — la licencia se activa sola

### Archivos necesarios en el proyecto

Para usar Wokwi en VS Code, tu proyecto debe tener:

```
firmware/esp32/
├── platformio.ini
├── diagram.json       # Esquemático
├── wokwi.toml         # Configuración de Wokwi
└── src/
    └── main.cpp
```

#### `diagram.json`

Define los componentes del circuito virtual. Ejemplo mínimo:

```json
{
  "version": 1,
  "author": "Tu Nombre",
  "editor": "wokwi",
  "parts": [
    {
      "type": "board-esp32-devkit-c-v4",
      "id": "esp",
      "top": 0,
      "left": 0,
      "attrs": {}
    }
  ],
  "connections": []
}
```

#### `wokwi.toml`

Le dice a Wokwi dónde está el binario compilado:

```toml
[wokwi]
version = 1
firmware = '.pio/build/esp32dev/firmware.bin'
elf = '.pio/build/esp32dev/firmware.elf'
```

⚠️ **Importante:** la ruta `esp32dev` debe coincidir con el nombre del entorno en `platformio.ini`. Si tu entorno se llama `esp32`, cambia a `.pio/build/esp32/`.

### Cómo correr la simulación

1. Compila el código primero: botón ✓ o `pio run`
2. Abre el archivo `diagram.json` en VS Code
3. `Cmd + Shift + P` → **"Wokwi: Start Simulator"**
4. Se abre el simulador en una pestaña de VS Code
5. Click en el botón **▶ verde** para arrancar

### El bug del monitor serial vacío

Si el monitor de Wokwi no muestra el output del ESP32:

**Solución 1:** Click DENTRO del monitor para enfocarlo, luego presiona Reset 🔄

**Solución 2:** Detén, cierra y reabre el simulador

**Solución 3:** Si nada funciona, usa wokwi.com en el navegador

---

## 🧩 Componentes que SÍ existen en Wokwi

Estos son los más útiles para este proyecto:

| Componente | ID en Wokwi |
|---|---|
| ESP32 DevKit | `board-esp32-devkit-c-v4` |
| LED | `wokwi-led` |
| Resistencia | `wokwi-resistor` |
| Pulsador | `wokwi-pushbutton` |
| Sensor ultrasónico (sustituto del ToF) | `wokwi-hc-sr04` |
| MPU6050 | `wokwi-mpu6050` |
| Pantalla OLED | `wokwi-ssd1306` |
| Analizador lógico | `wokwi-logic-analyzer` |
| Slide switch | `wokwi-slide-switch` |

### Componentes que NO existen (cuidado)

- ❌ `wokwi-l298n` o `wokwi-tb6612fng` (no hay drivers de motores nativos)
- ❌ `wokwi-dc-motor` (no hay motores DC simulables)
- ❌ `wokwi-vl53l0x` (no hay sensor ToF, usar HC-SR04 como sustituto)

Para drivers de motores en Wokwi, se simulan con LEDs que representan las señales de control.

---

## 📚 Recursos útiles

- [Documentación oficial de Wokwi](https://docs.wokwi.com/)
- [Lista de componentes disponibles](https://docs.wokwi.com/parts/)
- [Ejemplos de proyectos](https://wokwi.com/projects)

---

## 🆘 Problemas comunes

### "Wokwi no encuentra el firmware.bin"

- Verifica que compilaste primero (`pio run` o botón ✓)
- Verifica que la ruta en `wokwi.toml` coincide con tu carpeta de build
- Si tu env es `esp32dev` → ruta `.pio/build/esp32dev/firmware.bin`
- Si tu env es `esp32` → ruta `.pio/build/esp32/firmware.bin`

### "Los componentes no aparecen en el simulador"

Verifica que los `type` en `diagram.json` sean válidos (lista arriba). Wokwi ignora silenciosamente componentes inexistentes.

### "La simulación está pausada al abrirse"

Click en el botón **▶ verde** para arrancar. No corre automáticamente.

### "El monitor serial está vacío en VS Code"

Bug conocido en Mac. Soluciones (en orden):
1. Click dentro del monitor + Reset 🔄
2. Cerrar y reabrir simulador
3. Cambiar a wokwi.com en el navegador

### "Wokwi web no compila mi código"

Verifica:
- No tienes `#include <Arduino.h>` (Wokwi web no lo necesita, sí da error)
- No tienes errores de sintaxis (revisa el panel de errores debajo del editor)

---

## ✅ Checklist al terminar

- [ ] Tengo cuenta en Wokwi (vía GitHub o Google)
- [ ] Puedo abrir https://wokwi.com sin problemas
- [ ] (Opcional) Extensión Wokwi instalada y activada en VS Code
- [ ] Sé la diferencia entre wokwi.com y la extensión

---

[← Anterior: PlatformIO](03-platformio.md) | [Siguiente: Fritzing →](05-fritzing.md)

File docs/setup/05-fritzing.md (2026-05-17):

# 05 — Fritzing

> **Fritzing** es la herramienta para diseñar y documentar circuitos electrónicos. Lo usamos para crear los diagramas de conexión del robot.

---

## 🎯 ¿Qué es Fritzing?

Es un programa que permite:

- Diseñar circuitos en **vista de protoboard** (cómo se ven los cables reales)
- Generar **esquemáticos** (representación eléctrica formal)
- Diseñar **PCBs** (placas de circuito impreso)
- Exportar imágenes para documentación

Es muy usado en educación, hobby y prototipado rápido.

---

## 🆚 ¿Por qué Fritzing y no otro?

| Herramienta | Curva | Costo | Para qué |
|---|---|---|---|
| **Fritzing** | Baja | $8 USD (pago único) | Documentar circuitos visualmente |
| **KiCad** | Alta | Gratis | Diseñar PCBs profesionalmente |
| **EasyEDA** | Media | Gratis | PCBs (integrado con JLCPCB) |
| **TinkerCAD Circuits** | Muy baja | Gratis | Educación básica |
| **Altium Designer** | Muy alta | $$$ | Industria profesional |

**Fritzing** es la mejor opción para esta fase del proyecto:
- Vista de protoboard intuitiva
- Bueno para mostrar conexiones a otros
- Suficiente para validar el diseño antes de pasar a PCB

Cuando llegues a la etapa de PCB, migrarás a **KiCad** o **EasyEDA**.

---

## 📥 Instalación

### macOS

#### Opción 1: Versión oficial (pago)

1. Ve a https://fritzing.org/download/
2. Haz una donación (mínimo €8) para soportar el proyecto
3. Recibes un link de descarga al correo
4. Descarga el `.dmg`
5. Arrastra Fritzing a `Applications`

#### Opción 2: Versión gratuita antigua

Versiones más antiguas se encuentran en repositorios alternativos. **Funciona** pero tiene menos componentes y puede ser inestable en Mac con Apple Silicon.

### Linux

```bash
sudo apt install fritzing    # Ubuntu/Debian
sudo dnf install fritzing    # Fedora
```

### Windows

Igual que Mac, descarga el instalador de https://fritzing.org

---

## 🎨 Interfaz de Fritzing

Cuando abres un proyecto nuevo, ves esto:

```
┌─────────────────────────────────────────────────────────┐
│  Archivo  Editar  Vista  Parte  Ventana                  │
├─────────────────────────────────────────────────────────┤
│  [Breadboard]  [Schematic]  [PCB]                        │
├──────────────────────────────────┬──────────────────────┤
│                                  │                       │
│                                  │   Panel de            │
│       Área de trabajo            │   componentes        │
│       (aquí dibujas)             │                       │
│                                  │   CORE | MINE        │
│                                  │                       │
│                                  ├──────────────────────┤
│                                  │   Inspector          │
│                                  │   (propiedades del   │
│                                  │    componente        │
│                                  │    seleccionado)     │
│                                  │                       │
└──────────────────────────────────┴──────────────────────┘
```

### Las 3 vistas (pestañas arriba)

1. **Breadboard** — Vista realista con protoboard y cables. La más intuitiva.
2. **Schematic** — Esquemático eléctrico formal.
3. **PCB** — Diseño físico de placa de circuito impreso.

Las 3 vistas se actualizan automáticamente: si conectas algo en breadboard, aparece en las otras dos.

---

## 🧩 Componentes en Fritzing

### Las 3 pestañas del panel de componentes

- **CORE** — componentes incluidos por defecto (resistencias, LEDs, Arduino UNO, breadboard, etc.)
- **MINE** — componentes que importaste tú
- **All Parts** — todos juntos

### Componentes incluidos en este proyecto

Para evitar buscarlos uno por uno, este repo incluye los componentes custom en `hardware/fritzing-parts/`:

```
hardware/fritzing-parts/
├── ESP32_DevKit_V1.fzpz       # ESP32 DOIT 30 pines
├── TB6612FNG.fzpz             # Driver de motores
├── VL53L0X.fzpz               # Sensor ToF (Adafruit)
└── (otros si se agregan)
```

### Cómo importar componentes

#### Método 1: Drag & drop (recomendado)

1. Abre Finder y ve a `hardware/fritzing-parts/`
2. Tienes Fritzing abierto en otra ventana
3. **Arrastra los archivos `.fzpz`** sobre Fritzing
4. Aparecen en la pestaña **MINE**

#### Método 2: Menú

1. En Fritzing: **File → Open** (`Cmd + O`)
2. Selecciona el archivo `.fzpz`
3. Se importa automáticamente

---

## 🛠️ Operaciones básicas

### Atajos esenciales

| Acción | Atajo |
|---|---|
| Nuevo proyecto | `Cmd + N` |
| Guardar | `Cmd + S` |
| Acercar zoom | `Cmd + +` |
| Alejar zoom | `Cmd + -` |
| Ajustar a pantalla | `Cmd + 0` |
| Rotar componente 90° | Click derecho → Rotate 90° CW |
| Eliminar | Seleccionar + `Delete` |

### Cómo agregar un componente al área

1. Localiza el componente en el panel derecho (CORE o MINE)
2. **Click sostenido** y arrastra al área de trabajo
3. Suelta donde quieras colocarlo

### Cómo conectar componentes con cables

1. Click sostenido sobre el **círculo pequeño** de un pin
2. **Arrastra** hasta otro pin
3. Suelta cuando aparezca el indicador verde de conexión válida
4. Aparece un cable

### Cambiar color de cable

1. Click sobre el cable
2. En el **Inspector** (panel inferior derecho), busca el campo **color**
3. Selecciona el color deseado

### Doblar un cable

Click en algún punto intermedio del cable y arrastra para crear un "codo".

---

## 🎨 Convención de colores recomendada

Para mantener tus diagramas legibles:

| Función | Color | Por qué |
|---|---|---|
| GND (tierra) | Negro | Convención universal |
| 3.3V | Naranja | Diferenciar de 5V |
| 5V / VCC | Rojo | Convención |
| Batería + (7.4V) | Morado | Diferenciar de 5V |
| Señales digitales | Verde / Azul | Para datos |
| PWM | Amarillo | Para distinguir |
| Señales a motores | Blanco / Marrón | Output |

---

## 🔌 Cómo abrir el diagrama de este proyecto

Si ya hay un archivo `.fzz` en `hardware/`:

1. Abre Fritzing
2. **File → Open** (`Cmd + O`)
3. Navega a `hardware/motores-driver-esp32.fzz`
4. Click en **Open**

Si los componentes custom no aparecen, primero importa los `.fzpz` de `hardware/fritzing-parts/`.

---

## 📸 Exportar el diagrama como imagen

Para incluir en documentación o README:

1. **File → Export → as Image → PNG/SVG/PDF**
2. Selecciona resolución (300 dpi para impresión, 150 para web)
3. Guardar como `imagen.png`

Recomendado: exportar a **`docs/hardware/images/`** para usar en los `.md`.

---

## 🆘 Problemas comunes

### "Los componentes importados no aparecen en MINE"

**Solución:**
1. Cierra Fritzing
2. Vuelve a abrir
3. Importa los `.fzpz` nuevamente
4. Verifica en la pestaña **MINE**

### "Fritzing es muy lento en Apple Silicon (M1/M2/M3)"

Versiones antiguas de Fritzing no están optimizadas para chips ARM. Soluciones:

- Usar la versión oficial nueva (pagada)
- Reducir el zoom y simplificar el diagrama
- Cerrar otras aplicaciones para liberar RAM

### "Los cables se cruzan y el diagrama queda feo"

- Usa **codos** (click en mitad del cable + arrastrar)
- Mueve componentes con `arrastre` para mejor distribución
- Considera usar la vista **Schematic** que es más limpia para diagramas complejos

### "No encuentro un componente específico"

Si no está en CORE ni en MINE:
1. Busca en **https://github.com/sparkfun/Fritzing_Parts**
2. Busca en el foro: **https://forum.fritzing.org**
3. Descarga el `.fzpz` y arrástralo a Fritzing

### "Fritzing crashea al guardar"

Bug ocasional. Solución:
1. Guarda con **File → Save As** (no Save)
2. Da otro nombre temporal
3. Cierra y reabre

---

## 🚀 Cuando estés listo para PCB

Fritzing tiene vista PCB, pero no es ideal para producción real. Cuando llegues a fabricar un PCB:

1. Pásate a **KiCad** (gratis, profesional) o **EasyEDA** (online, fácil)
2. Re-dibuja el esquemático ahí
3. Diseña el ruteo del PCB
4. Exporta Gerbers
5. Manda a fabricar con **PCBWay** o **JLCPCB**

Fritzing es bueno para **documentar y validar conceptualmente**, pero para producción se usan herramientas más serias.

---

## ✅ Checklist al terminar

- [ ] Fritzing instalado
- [ ] Sé cambiar entre las 3 vistas (Breadboard, Schematic, PCB)
- [ ] Puedo importar componentes `.fzpz`
- [ ] Sé arrastrar componentes y conectar cables
- [ ] Sé exportar el diagrama como imagen

---

[← Anterior: Wokwi](04-wokwi.md) | [Siguiente: Git y GitHub →](06-git-github.md)

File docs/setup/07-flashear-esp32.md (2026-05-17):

# 07 — Flashear el ESP32

> Esta guía explica cómo subir (flashear) el código compilado al ESP32 físico, y cómo verificar que está funcionando correctamente.

---

## 🎯 ¿Qué significa "flashear"?

"Flashear" es la jerga embebida para **subir un firmware (binario) a la memoria flash del microcontrolador**. Es lo mismo que hace:

- Apple cuando actualiza iOS
- Tesla cuando actualiza tu auto (OTA)
- DJI con tu dron

La diferencia es que tú lo haces vía cable USB a tu chip.

---

## 📋 Antes de empezar

### Prerrequisitos

- [x] ESP32 DOIT DevKit V1 (o compatible)
- [x] Cable USB con **datos** (no solo carga)
- [x] PlatformIO instalado y funcionando
- [x] Código compilado exitosamente (`pio run` con `[SUCCESS]`)
- [x] Puerto USB libre en la Mac

### Verificar que el cable tiene datos

Los cables USB de "solo carga" son comunes y causan mucha confusión. Para verificar:

1. Conecta el ESP32 al Mac con tu cable
2. En el ESP32 debería encender un **LED rojo** (LED de power)
3. Ejecuta en terminal:
```bash
ls /dev/cu.*
```
4. Si aparece algo como `/dev/cu.usbserial-0001` → cable bueno
5. Si solo aparece `Bluetooth-Incoming-Port` → cable malo, prueba otro

---

## 🔌 Conectar el ESP32

### Pasos físicos

1. Toma el cable USB
2. El extremo **micro-USB** va al ESP32 (puerto trapezoidal pequeño)
3. El otro extremo (USB-A o USB-C) va al Mac
4. Asegúrate de que está bien insertado

### Qué deberías ver

- ✅ **LED rojo encendido** en la placa (LED de "power")
- ✅ Posiblemente un **LED azul parpadea** una vez (LED en GPIO 2)

Si el LED rojo no enciende:
- Prueba otro cable
- Prueba otro puerto USB del Mac
- Verifica que el ESP32 no tenga daños visibles

---

## 🔍 Verificar que macOS detecta el ESP32

### En terminal

```bash
ls /dev/cu.*
```

### Resultados posibles

#### ✅ Caso A: Detectado correctamente

```
/dev/cu.Bluetooth-Incoming-Port
/dev/cu.usbserial-0001
```

o similares con `wchusbserial` o `SLAB_USBtoUART`. **¡Puedes saltar a la sección "Flashear el código"!**

#### ❌ Caso B: Solo aparece Bluetooth

Significa que el sistema no detecta el ESP32. Posibles causas:

1. **Cable solo de carga** — prueba otro cable
2. **Falta driver USB-Serial** — sigue la sección siguiente

---

## 💾 Instalar driver USB-Serial (si hace falta)

El ESP32 DOIT V1 puede usar uno de dos chips USB-Serial:

### Identificar tu chip

Mira tu ESP32 cerca del puerto micro-USB. Hay un chip pequeño cuadrado:

- Si dice **"CP2102"** → driver de Silicon Labs
- Si dice **"CH340"** o **"CH340G"** → driver WCH

Si no lo ves bien, instala primero el CP2102 (es el más común en placas DOIT).

### Driver CP2102 (Silicon Labs)

1. Ve a: https://www.silabs.com/developers/usb-to-uart-bridge-vc-drivers
2. Acepta los términos
3. Descarga **"CP210x VCP Mac OSX Driver"**
4. Abre el `.dmg` descargado
5. Ejecuta el instalador
6. Te pedirá password del Mac
7. **Reinicia el Mac** (importante en macOS reciente)
8. Verifica:
```bash
ls /dev/cu.*
```

### Driver CH340 (WCH)

1. Ve a: https://github.com/WCHSoftGroup/ch34xser_macos
2. Descarga el `.dmg` desde la última release
3. Instala
4. En macOS reciente: **System Settings → Privacy & Security**
5. Verás un mensaje pidiendo permitir el driver — click en **"Allow"**
6. **Reinicia el Mac**
7. Verifica con `ls /dev/cu.*`

---

## 🚀 Flashear el código

### Asegúrate de estar en la carpeta correcta

```bash
cd "ruta/al/proyecto/firmware/esp32"
```

### Método 1: Por terminal (recomendado)

```bash
pio run --target upload
```

### Método 2: Botón en VS Code

En la **barra azul inferior** de VS Code, hay una flecha **→**. Pasa el mouse para confirmar que dice **"PlatformIO: Upload"** y haz click.

### Qué vas a ver

```
Processing esp32dev (platform: espressif32; board: esp32dev; framework: arduino)
--------------------------------------------------------------------------------
...
Configuring upload protocol...
CURRENT: upload_protocol = esptool
Looking for upload port...
Auto-detected: /dev/cu.usbserial-0001
Uploading .pio/build/esp32dev/firmware.bin
esptool.py v4.11.0
Serial port /dev/cu.usbserial-0001
Connecting....
Chip is ESP32-D0WD-V3 (revision v3.1)
Features: WiFi, BT, Dual Core, 240MHz...
MAC: xx:xx:xx:xx:xx:xx
Uploading stub...
...
Writing at 0x00010000... (10 %)
Writing at 0x00020000... (20 %)
...
Writing at 0x00051725... (100 %)
Hash of data verified.
Leaving...
Hard resetting via RTS pin...
============== [SUCCESS] Took 8.21 seconds ==============
```

**`[SUCCESS]` en verde = tu código está corriendo en hardware real.** 🎉

---

## 📺 Verificar que funciona — Monitor serial

### Abrir el monitor

```bash
pio device monitor
```

O click en el ícono **⚡** en la barra inferior de VS Code.

### Qué deberías ver

```
--- Terminal on /dev/cu.usbserial-0001 | 115200 8-N-1
--- Quit: Ctrl+C | Menu: Ctrl+T | Help: Ctrl+T followed by Ctrl+H

rst:0x1 (POWERON_RESET),boot:0x13 (SPI_FAST_FLASH_BOOT)
configsip: 0, SPIWP:0xee
...

=== Robot Diferencial ESP32 - Test Motores ===
Comandos disponibles:
  w = adelante   s = atras
  a = girar izq  d = girar der
  x = detener
  + = mas rapido - = mas lento
>> DETENIDO
```

### Si el monitor está vacío

Significa que te conectaste **después** de que el ESP32 arrancó (y se perdió el mensaje inicial). Soluciones:

1. **Presiona el botón EN (reset)** en la placa del ESP32
2. O ejecuta `Ctrl + T` seguido de `Ctrl + R` (reset desde el monitor)
3. Verás el mensaje aparecer

### Interactuar con el código

1. Click dentro del monitor (para que reciba lo que tipeas)
2. Escribe **`w`** y presiona Enter
3. Deberías ver:
```
>> ADELANTE
```

Prueba todos los comandos:

| Comando | Esperado |
|---|---|
| `w` | `>> ADELANTE` |
| `s` | `>> ATRAS` |
| `a` | `>> GIRO IZQUIERDA` |
| `d` | `>> GIRO DERECHA` |
| `x` | `>> DETENIDO` |
| `+` | `Velocidad: 220` |
| `-` | `Velocidad: 180` |

### Salir del monitor

`Ctrl + C`

---

## 🔬 Bonus: Verificar señales con multímetro

Si tienes multímetro, puedes confirmar que los pines del ESP32 están enviando las señales correctas (sin el TB6612FNG aún conectado).

### Test de pines de dirección

Modo del multímetro: **DC Voltage**

1. Pinza negra → cualquier pin **GND** del ESP32
2. Pinza roja → **GPIO 26** (AIN1)
3. En monitor serial, envía `w`. Mide:
   - GPIO 26 ≈ 3.3V (HIGH)
   - GPIO 27 ≈ 0V (LOW)
4. Envía `s`. Mide:
   - GPIO 26 ≈ 0V (LOW)
   - GPIO 27 ≈ 3.3V (HIGH)
5. Envía `x`. Ambos ≈ 0V.

### Test de pin PWM

Con `w` enviado, mide **GPIO 25** (PWMA):

- Multímetro común: ~2.5V (promedia el PWM)
- Osciloscopio: onda cuadrada a 1 kHz

Cambia velocidad con `+` y `-`, el voltaje promedio variará.

---

## 🆘 Problemas comunes

### "Connecting......" se queda colgado

El ESP32 está en modo raro. Solución:

1. Inicia el comando upload
2. **Mantén presionado el botón BOOT** (también llamado IO0) en la placa
3. Cuando empiece a escribir, **suelta BOOT**
4. La carga continúa normalmente

### "Wrong boot mode detected"

Similar al anterior. Solución:

1. Presiona el botón **EN** (reset)
2. Inmediatamente click en Upload
3. Si sigue, mantén **BOOT** durante todo el upload

### "Permission denied: /dev/cu.usbserial-XXXX"

Permisos del puerto serial:

```bash
sudo chmod 666 /dev/cu.usbserial-0001
```

### "esptool.py: command not found"

PlatformIO no está cargando esptool. Solución:

1. Cierra y reabre la terminal de VS Code
2. Verifica con `which pio`
3. Si todavía falla, reinstala PlatformIO

### "El ESP32 se reinicia constantemente"

Problemas posibles:

1. **Cable defectuoso** (no aporta suficiente corriente)
2. **Puerto USB del Mac saturado** — prueba otro puerto
3. **Código con bug** que causa crash — revisa logs en serial
4. **Watchdog activado** — el código tarda mucho en una función

### "Monitor serial muestra caracteres raros"

Velocidad del monitor incorrecta. Tu `platformio.ini` debe tener:

```ini
monitor_speed = 115200
```

Si pusiste otra velocidad, ajusta para que coincida con el `Serial.begin()` del código.

---

## 📊 Métricas que debes esperar

Cuando un upload es exitoso, verás:

| Métrica | Valor típico |
|---|---|
| Tamaño del firmware | 200-300 KB |
| Velocidad de upload | ~500 kbit/s |
| Tiempo total | 5-10 segundos |
| Uso de RAM | <20% (típico < 10%) |
| Uso de Flash | <30% (típico ~21%) |

Si excedes mucho estos números, tu código tiene algo extraño que conviene revisar.

---

## ✅ Checklist al terminar

- [ ] El ESP32 está conectado y el LED rojo encendido
- [ ] `ls /dev/cu.*` muestra un puerto `usbserial`
- [ ] (Si hizo falta) Driver USB-Serial instalado
- [ ] `pio run --target upload` termina con `[SUCCESS]`
- [ ] Monitor serial muestra el mensaje de bienvenida
- [ ] Puedo enviar comandos y ver respuestas

---

## 🎓 Resumen del flujo

```
1. Escribir código en src/main.cpp
2. pio run                           ← compilar
3. pio run --target upload           ← flashear
4. pio device monitor                ← ver output
5. (Iterar)
```

Este es **exactamente el ciclo profesional** de desarrollo embebido. Lo que aprendiste aquí te sirve para cualquier proyecto con ESP32, ESP8266, STM32 y muchos otros chips.

---

[← Anterior: Git y GitHub](06-git-github.md) | [Volver al índice](README.md)

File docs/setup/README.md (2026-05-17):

# Guías de Configuración del Entorno

> Esta sección documenta **paso a paso** cómo configurar todas las herramientas necesarias para trabajar en este proyecto desde cero. Si descargaste el repositorio y no sabes por dónde empezar, este es tu punto de partida.

---

## 🎯 Para quién es esta documentación

- Quien clona el repositorio por primera vez
- Quien quiere replicar el entorno de desarrollo
- Quien necesita reinstalar todo tras un cambio de equipo
- Quien quiere entender el "por qué" detrás de cada herramienta

---

## 📋 Orden recomendado de lectura

1. **[Prerrequisitos](01-prerequisitos.md)** — Sistema operativo, hardware y cuentas necesarias
2. **[VS Code](02-vscode.md)** — Editor de código principal
3. **[PlatformIO](03-platformio.md)** — Sistema de build para microcontroladores
4. **[Wokwi](04-wokwi.md)** — Simulador electrónico
5. **[Fritzing](05-fritzing.md)** — Diseño de circuitos
6. **[Git y GitHub](06-git-github.md)** — Versionamiento de código
7. **[Flashear el ESP32](07-flashear-esp32.md)** — Cargar código en hardware real

---

## ⏱️ Tiempo estimado

| Etapa | Tiempo |
|---|---|
| Setup completo desde cero | 1-2 horas |
| Setup mínimo (solo firmware) | 30-45 min |
| Reinstalar todo | 45 min |

---

## 🖥️ Sistema operativo soportado

Este proyecto se desarrolló en **macOS**. Las guías están optimizadas para Mac (Intel y Apple Silicon).

Para Linux o Windows, los pasos son similares pero los comandos varían. Las herramientas (VS Code, PlatformIO, Wokwi, Fritzing) son multiplataforma.

---

## 🆘 Solución de problemas comunes

Cada guía incluye al final una sección de **"Problemas comunes"** con los errores típicos y sus soluciones.

Si encuentras un problema nuevo, agrégalo a la guía correspondiente para que otros se beneficien.

---

## 📁 Estructura del repositorio (referencia)

```
Robot diferencial iOS/
├── cad/                    # Diseños 3D del chasis
├── docs/                   # Documentación (estás aquí)
│   ├── setup/              # Guías de instalación
│   ├── hardware/           # Documentación de componentes
│   ├── firmware/           # Arquitectura del código
│   └── bitacoras/          # Diario de desarrollo
├── firmware/
│   └── esp32/              # Proyecto PlatformIO
│       ├── src/main.cpp
│       ├── platformio.ini
│       ├── diagram.json    # Wokwi
│       └── wokwi.toml
├── hardware/
│   ├── fritzing-parts/     # Componentes custom de Fritzing
│   └── *.fzz               # Diagramas de circuito
├── ios-app/                # App iOS (futuro)
├── media/                  # Fotos y videos
└── simulation/             # Archivos auxiliares de simulación
```

---

*Documentación mantenida por: David Zárate*
*Última actualización: mayo 2026*

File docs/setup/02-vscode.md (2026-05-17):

# 02 — VS Code

> **Visual Studio Code** es el editor de código principal del proyecto. Es gratis, multiplataforma y altamente extensible.

---

## 🎯 ¿Por qué VS Code?

- **Gratis y open source**
- **Multiplataforma** (Mac, Linux, Windows)
- **Extensiones para todo:** PlatformIO, Wokwi, Git, Markdown, etc.
- **Terminal integrada** — no necesitas alternar ventanas
- **Estándar de la industria** — saberlo usar te sirve en cualquier trabajo de programación

---

## 📥 Instalación

### macOS

#### Opción 1: Descarga directa (recomendado)

1. Abre el navegador y ve a: **https://code.visualstudio.com**
2. Click en **"Download Mac Universal"** (funciona en Intel y Apple Silicon)
3. Se descarga un archivo `.zip`
4. Doble click al `.zip` para extraerlo
5. Aparece **"Visual Studio Code.app"**
6. **Arrástralo a la carpeta `Applications`**
7. Listo

#### Opción 2: Homebrew (si lo usas)

```bash
brew install --cask visual-studio-code
```

### Linux

```bash
# Ubuntu/Debian
sudo snap install code --classic

# Fedora
sudo rpm --import https://packages.microsoft.com/keys/microsoft.asc
sudo dnf install code
```

### Windows

1. Ve a https://code.visualstudio.com
2. Descarga el instalador `.exe`
3. Ejecuta y sigue el asistente
4. Marca **"Add to PATH"** durante la instalación

---

## 🚀 Primer arranque

1. Abre VS Code desde Launchpad (Mac) o el menú de aplicaciones
2. La primera vez aparece la pantalla de bienvenida con opciones para:
   - Cambiar tema (claro/oscuro)
   - Configurar atajos de teclado
   - Instalar extensiones

Puedes saltar todo esto por ahora.

---

## 🧩 Extensiones requeridas para el proyecto

Las extensiones son "plugins" que agregan funcionalidad. Las que necesitamos:

### 1. PlatformIO IDE (esencial)

**Para qué:** Compilar y subir código al ESP32.

**Cómo instalar:**
1. Click en el ícono de extensiones (panel izquierdo): cuadritos apilados, o `Cmd + Shift + X`
2. En la barra de búsqueda escribe: `PlatformIO IDE`
3. Click en **"Install"** sobre la extensión oficial de PlatformIO
4. ⏳ Espera 3-5 minutos (es grande, descarga muchas herramientas)
5. Cuando termine, VS Code te pedirá **reiniciar** — acepta
6. Al reabrir, verás un ícono de "carita de alien" 👽 en la barra lateral

### 2. Wokwi Simulator (opcional)

**Para qué:** Simular el ESP32 directamente en VS Code.

**Cómo instalar:**
1. En extensiones, busca: `Wokwi`
2. Instala **"Wokwi Simulator"** del autor "Wokwi"
3. Después de instalar, sigue los pasos en la [Guía de Wokwi](04-wokwi.md) para activar la licencia gratuita

⚠️ **Nota:** Esta extensión a veces tiene bugs en Mac. La alternativa es usar [wokwi.com](https://wokwi.com) en el navegador.

### 3. C/C++ (automática)

Esta extensión la instala PlatformIO automáticamente. Provee autocompletado y resaltado de C++.

### 4. Markdown Preview Enhanced (recomendada)

**Para qué:** Ver los archivos `.md` con formato bonito.

**Cómo instalar:** Busca `Markdown Preview Enhanced` e instala.

**Cómo usar:** Abre cualquier archivo `.md` y presiona `Cmd + K` seguido de `V` para ver el preview.

### 5. GitLens (opcional, muy útil)

**Para qué:** Ver historial de Git directamente en el editor.

Busca `GitLens — Git supercharged` e instala.

---

## ⚙️ Configuración recomendada

### Atajos de teclado básicos

| Acción | Atajo Mac | Atajo Windows/Linux |
|---|---|---|
| Abrir terminal | `Ctrl + ñ` | `Ctrl + ñ` |
| Buscar archivo | `Cmd + P` | `Ctrl + P` |
| Paleta de comandos | `Cmd + Shift + P` | `Ctrl + Shift + P` |
| Guardar | `Cmd + S` | `Ctrl + S` |
| Buscar en archivo actual | `Cmd + F` | `Ctrl + F` |
| Buscar en todo el proyecto | `Cmd + Shift + F` | `Ctrl + Shift + F` |
| Comentar línea | `Cmd + /` | `Ctrl + /` |
| Duplicar línea | `Shift + Option + ↓` | `Shift + Alt + ↓` |

### Configuración recomendada (settings.json)

Abre la paleta de comandos (`Cmd + Shift + P`) → escribe **"Preferences: Open Settings (JSON)"** → presiona Enter.

Pega esto al final del archivo (antes de la última `}`):

```json
{
    "editor.fontSize": 14,
    "editor.tabSize": 2,
    "editor.formatOnSave": true,
    "files.autoSave": "afterDelay",
    "files.autoSaveDelay": 1000,
    "terminal.integrated.fontSize": 13,
    "workbench.colorTheme": "Default Dark Modern"
}
```

Esto activa:
- Auto-guardado cada segundo
- Formateo automático al guardar
- Tamaño de fuente cómodo

---

## 📂 Cómo abrir el proyecto

### Si ya clonaste el repositorio

1. Abre VS Code
2. Menú **File → Open Folder...**
3. Navega hasta la carpeta `Robot diferencial iOS`
4. Click en **"Open"**

### Si vas a clonar el repositorio desde VS Code

1. Abre VS Code
2. `Cmd + Shift + P` → escribe **"Git: Clone"**
3. Pega la URL del repositorio
4. Selecciona dónde guardarlo

⚠️ **Importante para este proyecto:**

Cuando trabajes con PlatformIO, **abre la carpeta `firmware/esp32/`** directamente, no la raíz del proyecto. PlatformIO espera ver `platformio.ini` en la raíz del workspace.

```bash
# Desde terminal
cd "ruta/al/proyecto/firmware/esp32"
code .
```

---

## 🆘 Problemas comunes

### "VS Code no detecta PlatformIO después de instalarlo"

**Solución:**
1. Cierra VS Code completamente
2. Vuelve a abrirlo
3. Espera 1-2 minutos al primer arranque (PlatformIO se inicializa)

### "Las extensiones se ven en gris / inactivas"

**Solución:** Click derecho sobre la extensión → "Enable".

### "VS Code está en otro idioma y quiero cambiarlo"

1. `Cmd + Shift + P`
2. Escribe: `Configure Display Language`
3. Selecciona el idioma (puede pedir instalar el paquete de idioma)
4. Reinicia VS Code

### "No encuentro la terminal"

Menú **Terminal → New Terminal**, o atajo `` Ctrl + n ``.

---

## ✅ Checklist al terminar

- [ ] VS Code instalado y abriendo correctamente
- [ ] Extensión PlatformIO IDE instalada
- [ ] (Opcional) Extensión Wokwi Simulator instalada
- [ ] (Opcional) Markdown Preview Enhanced instalada
- [ ] Sabes abrir la terminal integrada
- [ ] Sabes abrir la paleta de comandos

---

[← Anterior: Prerrequisitos](01-prerequisitos.md) | [Siguiente: PlatformIO →](03-platformio.md)

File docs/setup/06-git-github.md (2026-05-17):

# 06 — Git y GitHub

> **Git** es el sistema de control de versiones más usado del mundo. **GitHub** es la plataforma online donde se alojan repositorios Git. Juntos te permiten guardar el historial completo de tu proyecto y compartirlo.

---

## 🎯 ¿Por qué Git y GitHub?

- **Historial completo** del código (puedes volver a cualquier punto del pasado)
- **Trabajar desde múltiples computadoras** sin perder cambios
- **Compartir con otros** o que descarguen el proyecto
- **Respaldo automático** en la nube
- **Estándar absoluto** en la industria

Sin Git, perder código es cuestión de tiempo. Con Git, casi imposible.

---

## 📥 Instalación de Git

### macOS

Git viene **preinstalado** en macOS reciente. Verifica:

```bash
git --version
```

Debería mostrar algo como:
```
git version 2.39.5 (Apple Git-154)
```

Si no está instalado, el sistema te pedirá instalar las **Command Line Tools** automáticamente. Acepta y espera 5 minutos.

#### Instalación manual (más reciente)

```bash
brew install git
```

### Linux

```bash
sudo apt install git    # Ubuntu/Debian
sudo dnf install git    # Fedora
```

### Windows

Descarga desde https://git-scm.com — instala con opciones por defecto.

---

## ⚙️ Configuración inicial de Git

Solo se hace **una vez por computadora**.

```bash
git config --global user.name "Tu Nombre"
git config --global user.email "tucorreo@example.com"
git config --global init.defaultBranch main
```

Usa el mismo email que en tu cuenta de GitHub.

---

## 🐙 GitHub

### Crear cuenta

1. Ve a **https://github.com**
2. Click en **"Sign up"**
3. Completa el registro con tu email
4. Verifica el correo

### Autenticación: SSH vs HTTPS

Para que tu Mac pueda **subir** código a GitHub, necesitas autenticarte. Hay dos métodos:

#### Opción A: HTTPS + Personal Access Token (más fácil)

1. En GitHub: **Settings → Developer settings → Personal access tokens → Tokens (classic)**
2. **Generate new token**
3. Marca permisos: `repo` (todos los sub-permisos)
4. Expiración: 90 días (o lo que prefieras)
5. **Generate token**
6. **Copia el token** (no se muestra otra vez)
7. La próxima vez que hagas `git push`, te pedirá usuario (tu email) y contraseña (pega el token)

#### Opción B: SSH (más profesional)

1. Genera una llave SSH:
```bash
ssh-keygen -t ed25519 -C "tucorreo@example.com"
```
2. Acepta los defaults (Enter, Enter, Enter)
3. Copia la llave pública:
```bash
cat ~/.ssh/id_ed25519.pub | pbcopy
```
4. En GitHub: **Settings → SSH and GPG keys → New SSH key**
5. Pega la llave y guarda
6. Verifica con:
```bash
ssh -T git@github.com
```
   Debería decir: `Hi <usuario>! You've successfully authenticated...`

**Recomendación:** Si es tu primera vez, usa HTTPS + token. Si vas a usar Git mucho, configura SSH.

---

## 📂 Conceptos clave de Git

### Repositorio (repo)

Una carpeta versionada por Git. Tiene una subcarpeta oculta `.git/` que guarda todo el historial.

### Commit

Una "foto" del estado de los archivos en un momento. Cada commit tiene:
- Un mensaje descriptivo
- Una fecha
- Un autor
- Un hash único

### Branch (rama)

Una línea paralela de desarrollo. La principal se llama `main` o `master`.

### Push y Pull

- **Push:** subir cambios locales al repositorio remoto (GitHub)
- **Pull:** descargar cambios del remoto al local

### Remote

El repositorio "espejo" en la nube. Típicamente se llama `origin`.

---

## 🛠️ Flujo básico de trabajo

### Caso 1: Empezar un proyecto nuevo en local y subirlo

```bash
# 1. Crear carpeta y entrar
mkdir mi-proyecto
cd mi-proyecto

# 2. Iniciar Git
git init

# 3. Crear archivos, escribir código
echo "# Mi proyecto" > README.md

# 4. Agregar archivos al "stage"
git add .

# 5. Hacer el primer commit
git commit -m "Initial commit"

# 6. Crear el repo en GitHub (vía web)
# 7. Conectar tu repo local con GitHub
git remote add origin https://github.com/tu-usuario/mi-proyecto.git
git branch -M main

# 8. Subir
git push -u origin main
```

### Caso 2: Clonar un repo existente (lo más común)

```bash
# Clonar
git clone https://github.com/tu-usuario/Robot-diferencial-iOS.git

# Entrar a la carpeta
cd Robot-diferencial-iOS

# Listo, ya tienes todo el proyecto
```

### Caso 3: Trabajar día a día

```bash
# 1. Antes de empezar, trae los últimos cambios del remoto
git pull

# 2. Trabaja: edita archivos, escribe código

# 3. Ver qué cambios hiciste
git status
git diff

# 4. Agregar cambios al stage
git add .                  # Todo
git add archivo.txt        # Solo un archivo

# 5. Hacer commit
git commit -m "Agregué función de evasión de obstáculos"

# 6. Subir al remoto
git push
```

---

## 📋 Comandos esenciales

| Comando | Descripción |
|---|---|
| `git status` | Ver estado del repo |
| `git log` | Ver historial de commits |
| `git log --oneline` | Historial compacto |
| `git diff` | Ver cambios no comiteados |
| `git add archivo` | Agregar un archivo al stage |
| `git add .` | Agregar todo al stage |
| `git commit -m "msg"` | Hacer commit |
| `git push` | Subir al remoto |
| `git pull` | Bajar del remoto |
| `git branch` | Listar ramas |
| `git checkout -b nueva-rama` | Crear y cambiar a nueva rama |
| `git merge rama` | Fusionar rama con la actual |
| `git reset HEAD~1` | Deshacer el último commit (mantiene cambios) |
| `git stash` | Guardar cambios temporalmente |

---

## 📝 Buenas prácticas de mensajes de commit

### ❌ Mal

```
fixes
asdfasdf
"trabajo del día"
```

### ✅ Bien

```
Agregar función motorA() con control PWM
Corregir lectura de encoder en GPIO 34
Actualizar pinout del TB6612FNG en documentación
```

### Convención "Conventional Commits"

```
feat: agregar lectura de MPU-6050
fix: corregir polaridad en motor B
docs: actualizar README con instrucciones de instalación
refactor: separar lógica de motores en módulo aparte
test: agregar test de control de velocidad
chore: actualizar versión de librería Adafruit_MPU6050
```

---

## 📄 El archivo `.gitignore`

Lista de archivos que **NO** se suben al repo. Para este proyecto:

```
# PlatformIO build files
.pio/
.vscode/.browse.c_cpp.db*
.vscode/c_cpp_properties.json
.vscode/launch.json
.vscode/ipch

# Mac
.DS_Store

# Backups
*.bak
*~

# Sistema
.env

# Sensibles
secrets.h
config.json
```

Si tu repo aún no tiene `.gitignore`, créalo en la raíz con ese contenido.

---

## 🔧 Configuración recomendada para este proyecto

### Estructura del repo

Si vas a hacer fork o tu propio repo, este es el `.gitignore` óptimo:

```bash
# Ejecutar desde la raíz del proyecto
cat > .gitignore << 'EOF'
# PlatformIO
.pio/
.vscode/.browse.c_cpp.db*
.vscode/c_cpp_properties.json
.vscode/launch.json
.vscode/ipch

# macOS
.DS_Store
.AppleDouble
.LSOverride

# Fritzing
*.fzz~
*.bak

# CAD temp
*.bak.*

# Build outputs
build/
dist/

# IDE
.idea/
*.swp
EOF
```

---

## 🆘 Problemas comunes

### "Permission denied (publickey)"

Tu Mac no tiene autenticación configurada. Sigue la sección de **Autenticación** arriba.

### "fatal: not a git repository"

Estás en una carpeta que no es un repo Git. Ejecuta `git init` o `cd` a la carpeta correcta.

### "Updates were rejected because the remote contains work..."

Alguien (o tú desde otra compu) subió cambios después de tu último pull. Solución:

```bash
git pull --rebase
git push
```

### "I accidentally committed sensitive data"

Si subiste contraseñas o tokens por error:

1. **Cambia las contraseñas/tokens** inmediatamente (el daño ya está hecho)
2. Para limpiar el historial:
```bash
git rm --cached archivo-sensible
git commit -m "Eliminar archivo sensible"
git push
```

Pero el archivo sigue en el historial. Para borrarlo completamente, usa `git filter-repo` o `BFG Repo-Cleaner`.

### "Quiero deshacer cambios locales sin perder nada"

```bash
git stash         # Guarda cambios temporalmente
git pull          # Trae cambios remotos
git stash pop     # Restaura tus cambios
```

---

## 🎓 Recursos para profundizar

- [Pro Git Book (gratis)](https://git-scm.com/book/en/v2)
- [Aprende Git con Atlassian](https://www.atlassian.com/git/tutorials)
- [Oh Shit, Git!?! (cuando algo sale mal)](https://ohshitgit.com/)

---

## ✅ Checklist al terminar

- [ ] Git instalado y `git --version` funciona
- [ ] `user.name` y `user.email` configurados globalmente
- [ ] Cuenta de GitHub creada
- [ ] Autenticación configurada (token HTTPS o llave SSH)
- [ ] Sé hacer `git clone`, `git add`, `git commit`, `git push`, `git pull`
- [ ] Entiendo qué hace `.gitignore`

---

[← Anterior: Fritzing](05-fritzing.md) | [Siguiente: Flashear ESP32 →](07-flashear-esp32.md)

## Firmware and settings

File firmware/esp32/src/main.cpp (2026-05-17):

#include <Arduino.h>

// ============================================================
//  Robot Diferencial ESP32 - Control de Motores
//  Etapa 1: Driver de motores (TB6612FNG / L298N stand-in)
// ============================================================

// ---------- PINES MOTOR A (Izquierdo) ----------
#define PWMA 25
#define AIN1 26
#define AIN2 27

// ---------- PINES MOTOR B (Derecho) ----------
#define PWMB 33
#define BIN1 14
#define BIN2 12

// ---------- STBY (solo TB6612 real) ----------
#define STBY 13

// ---------- LEDs indicadores ----------
#define LED_FWD 2
#define LED_BWD 4

// ---------- CONFIGURACION PWM (ESP32 LEDC) ----------
const int FREQ_PWM = 1000;
const int RES_PWM = 8;
const int CANAL_PWMA = 0;
const int CANAL_PWMB = 1;

int velocidad = 200;

// ---------- DECLARACION DE FUNCIONES ----------
void motorA(int vel);
void motorB(int vel);
void adelante();
void atras();
void girarIzquierda();
void girarDerecha();
void detener();

// ============================================================
//  SETUP
// ============================================================
void setup()
{
  Serial.begin(115200);
  delay(500);
  Serial.println("\n=== Robot Diferencial ESP32 - Test Motores ===");

  pinMode(AIN1, OUTPUT);
  pinMode(AIN2, OUTPUT);
  pinMode(BIN1, OUTPUT);
  pinMode(BIN2, OUTPUT);
  pinMode(STBY, OUTPUT);
  pinMode(LED_FWD, OUTPUT);
  pinMode(LED_BWD, OUTPUT);

  ledcSetup(CANAL_PWMA, FREQ_PWM, RES_PWM);
  ledcSetup(CANAL_PWMB, FREQ_PWM, RES_PWM);
  ledcAttachPin(PWMA, CANAL_PWMA);
  ledcAttachPin(PWMB, CANAL_PWMB);

  digitalWrite(STBY, HIGH);

  Serial.println("Comandos disponibles:");
  Serial.println("  w = adelante   s = atras");
  Serial.println("  a = girar izq  d = girar der");
  Serial.println("  x = detener");
  Serial.println("  + = mas rapido - = mas lento");

  detener();
}

// ============================================================
//  FUNCIONES DE MOVIMIENTO
// ============================================================
void motorA(int vel)
{
  if (vel >= 0)
  {
    digitalWrite(AIN1, HIGH);
    digitalWrite(AIN2, LOW);
    ledcWrite(CANAL_PWMA, vel);
  }
  else
  {
    digitalWrite(AIN1, LOW);
    digitalWrite(AIN2, HIGH);
    ledcWrite(CANAL_PWMA, -vel);
  }
}

void motorB(int vel)
{
  if (vel >= 0)
  {
    digitalWrite(BIN1, HIGH);
    digitalWrite(BIN2, LOW);
    ledcWrite(CANAL_PWMB, vel);
  }
  else
  {
    digitalWrite(BIN1, LOW);
    digitalWrite(BIN2, HIGH);
    ledcWrite(CANAL_PWMB, -vel);
  }
}

void adelante()
{
  motorA(velocidad);
  motorB(velocidad);
  digitalWrite(LED_FWD, HIGH);
  digitalWrite(LED_BWD, LOW);
  Serial.println(">> ADELANTE");
}

void atras()
{
  motorA(-velocidad);
  motorB(-velocidad);
  digitalWrite(LED_FWD, LOW);
  digitalWrite(LED_BWD, HIGH);
  Serial.println(">> ATRAS");
}

void girarIzquierda()
{
  motorA(-velocidad);
  motorB(velocidad);
  digitalWrite(LED_FWD, HIGH);
  digitalWrite(LED_BWD, HIGH);
  Serial.println(">> GIRO IZQUIERDA");
}

void girarDerecha()
{
  motorA(velocidad);
  motorB(-velocidad);
  digitalWrite(LED_FWD, HIGH);
  digitalWrite(LED_BWD, HIGH);
  Serial.println(">> GIRO DERECHA");
}

void detener()
{
  motorA(0);
  motorB(0);
  digitalWrite(LED_FWD, LOW);
  digitalWrite(LED_BWD, LOW);
  Serial.println(">> DETENIDO");
}

// ============================================================
//  LOOP PRINCIPAL
// ============================================================
void loop()
{
  if (Serial.available())
  {
    char c = Serial.read();
    switch (c)
    {
    case 'w':
      adelante();
      break;
    case 's':
      atras();
      break;
    case 'a':
      girarIzquierda();
      break;
    case 'd':
      girarDerecha();
      break;
    case 'x':
      detener();
      break;
    case '+':
      velocidad = min(255, velocidad + 20);
      Serial.print("Velocidad: ");
      Serial.println(velocidad);
      break;
    case '-':
      velocidad = max(0, velocidad - 20);
      Serial.print("Velocidad: ");
      Serial.println(velocidad);
      break;
    }
  }
}

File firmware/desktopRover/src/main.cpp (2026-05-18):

#include <Arduino.h>
#include <BLEDevice.h>
#include <BLEServer.h>
#include <BLEUtils.h>
#include <BLE2902.h>

// ===== UUIDs Nordic UART Service (NUS) =====
#define SERVICE_UUID "6e400001-b5a3-f393-e0a9-e50e24dcca9e"
#define CHARACTERISTIC_RX "6e400002-b5a3-f393-e0a9-e50e24dcca9e" // iPhone -> ESP32
#define CHARACTERISTIC_TX "6e400003-b5a3-f393-e0a9-e50e24dcca9e" // ESP32 -> iPhone

#define DEVICE_NAME "DesktopRover"
#define LED_PIN 2 // LED interno del ESP32 DevKit

BLEServer *pServer = nullptr;
BLECharacteristic *pTxCharacteristic = nullptr;
bool deviceConnected = false;
bool oldDeviceConnected = false;

// ===== Helper para enviar respuestas =====
void sendResponse(const String &msg)
{
  if (deviceConnected && pTxCharacteristic)
  {
    pTxCharacteristic->setValue(msg.c_str());
    pTxCharacteristic->notify();
    Serial.printf("[TX] %s\n", msg.c_str());
  }
}

// ===== Callbacks de conexión =====
class ServerCallbacks : public BLEServerCallbacks
{
  void onConnect(BLEServer *pServer) override
  {
    deviceConnected = true;
    Serial.println("[BLE] Cliente conectado");
  }

  void onDisconnect(BLEServer *pServer) override
  {
    deviceConnected = false;
    Serial.println("[BLE] Cliente desconectado");
  }
};

// ===== Callback de comandos recibidos =====
class RxCallbacks : public BLECharacteristicCallbacks
{
  void onWrite(BLECharacteristic *pCharacteristic) override
  {
    String value = pCharacteristic->getValue().c_str();
    value.trim();

    if (value.length() == 0)
      return;

    Serial.printf("[RX] %s\n", value.c_str());

    // Procesar comandos
    if (value == "PING")
    {
      sendResponse("PONG");
    }
    else if (value == "LED_ON")
    {
      digitalWrite(LED_PIN, HIGH);
      sendResponse("LED:1");
    }
    else if (value == "LED_OFF")
    {
      digitalWrite(LED_PIN, LOW);
      sendResponse("LED:0");
    }
    else if (value == "STATUS")
    {
      String resp = "OK,uptime=" + String(millis() / 1000);
      sendResponse(resp);
    }
    else
    {
      sendResponse("ERR:UNKNOWN_CMD");
    }
  }
};

void setup()
{
  Serial.begin(115200);
  delay(500);
  Serial.println("\n=== DesktopRover BLE iniciando ===");

  pinMode(LED_PIN, OUTPUT);
  digitalWrite(LED_PIN, LOW);

  // Inicializar BLE
  BLEDevice::init(DEVICE_NAME);

  // Crear servidor
  pServer = BLEDevice::createServer();
  pServer->setCallbacks(new ServerCallbacks());

  // Crear servicio
  BLEService *pService = pServer->createService(SERVICE_UUID);

  // Characteristic TX (ESP32 -> iPhone) con notify
  pTxCharacteristic = pService->createCharacteristic(
      CHARACTERISTIC_TX,
      BLECharacteristic::PROPERTY_NOTIFY);
  pTxCharacteristic->addDescriptor(new BLE2902());

  // Characteristic RX (iPhone -> ESP32) con write
  BLECharacteristic *pRxCharacteristic = pService->createCharacteristic(
      CHARACTERISTIC_RX,
      BLECharacteristic::PROPERTY_WRITE | BLECharacteristic::PROPERTY_WRITE_NR);
  pRxCharacteristic->setCallbacks(new RxCallbacks());

  // Iniciar servicio
  pService->start();

  // Iniciar advertising
  BLEAdvertising *pAdvertising = BLEDevice::getAdvertising();
  pAdvertising->addServiceUUID(SERVICE_UUID);
  pAdvertising->setScanResponse(true);
  pAdvertising->setMinPreferred(0x06); // mejor compatibilidad con iPhone
  pAdvertising->setMinPreferred(0x12);
  BLEDevice::startAdvertising();

  Serial.printf("[BLE] Advertising como '%s'\n", DEVICE_NAME);
  Serial.println("[BLE] Esperando conexión del iPhone...");
}

void loop()
{
  // Re-iniciar advertising tras desconexión
  if (!deviceConnected && oldDeviceConnected)
  {
    delay(500);
    pServer->startAdvertising();
    Serial.println("[BLE] Re-advertising");
    oldDeviceConnected = deviceConnected;
  }
  if (deviceConnected && !oldDeviceConnected)
  {
    oldDeviceConnected = deviceConnected;
  }

  // Telemetría de prueba cada 2 segundos
  static uint32_t lastTelemetry = 0;
  if (deviceConnected && millis() - lastTelemetry > 2000)
  {
    lastTelemetry = millis();
    String t = "HEARTBEAT," + String(millis());
    sendResponse(t);
  }

  delay(10);
}

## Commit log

2026-05-17 simulación del esp32
2026-05-17 Se añade simulación
    [motor-driver-esp32.fzz]
2026-05-17 Se añade diagrama de conexión de los motores
2026-05-17 Se añaden archivos de la conexión de los motores
    [motor-driver-esp32-conection.fzz, motor-driver-esp32.fzz]
2026-05-17 Add comprehensive setup guides and environment docs
    Introduces detailed, step-by-step documentation for environment setup, covering prerequisites, tool installation (VS Code, PlatformIO, Wokwi, Fritzing), Git/GitHub usage, and ESP32 flashing. Aims to streamline onboarding, reduce setup issues, and provide troubleshooting for common pitfalls. Updates repository structure references and example configuration, enhancing clarity for new contributors.
2026-05-18 Se añade aplicación ios que controla un led
2026-05-18 Se añade manager de conexión bluetooth
